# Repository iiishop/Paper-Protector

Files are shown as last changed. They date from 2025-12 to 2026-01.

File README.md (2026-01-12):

# Paper Protector

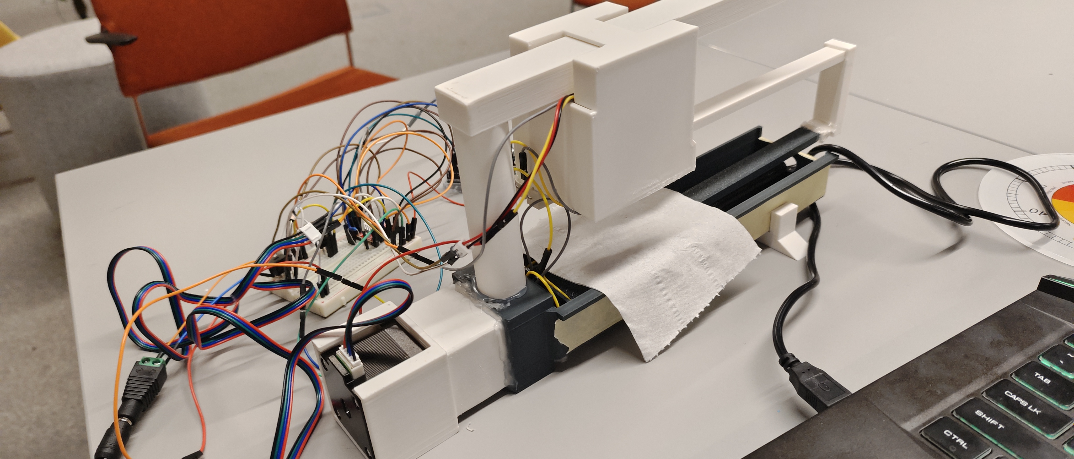
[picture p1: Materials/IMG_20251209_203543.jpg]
Paper Protector Prototype


---

## Video Demonstration

**Watch the system in action**: [Paper Protector Demo on Bilibili](https://www.bilibili.com/video/BV1xwraBiE8S)

*The video file is also available in this repository at [`Materials/QQ视频20260112051459 (online-video-cutter.com).mp4`](https://github.com/iiishop/Paper-Protector/blob/main/Materials/QQ%E8%A7%86%E9%A2%9120260112051459%20(online-video-cutter.com).mp4), but GitHub may not display it directly due to file size. Please use the Bilibili link above for online viewing.*

---

## 1. What it does

This project is an automated paper preservation system that detects and removes localized moisture from documents through precision scanning and targeted thermal intervention.

**Scanning Mode**: The device performs incremental X-axis scanning with a NEMA 17 stepper motor, moving at 1.498mm per revolution. During the scan:
- **DHT22 sensor** (Phase 2): Monitors real-time humidity and temperature with EMA filtering (α=0.3) to compensate for sensor lag.
- **AS7341-V2 NIR sensor** (Phase 1, damaged): Previously detected moisture at 60Hz via water molecule absorption spectra using 850nm IR LEDs.
- **Forced-induction sampling**: A 5015 fan at 50% power actively pushes moisture through paper fibres toward the sensor, accelerating response time from ~5s to ~2s.
- **Position tracking**: Non-blocking motor control ensures each reading corresponds to a precise spatial coordinate, generating ~140 data points over a 210mm path.

**Wet Spot Detection**: The web interface analyzes scan data using gradient-based dynamic threshold adjustment:
- **Humidity gradient calculation**: Detects rising/falling trends to predict true moisture levels.
- **Hysteresis compensation**: Lowers threshold by 30% during rising trends; raises by 10% during falling trends to avoid false positives.
- **Spatial mapping**: Blue circular markers with percentage overlays appear on the digital twin interface, indicating exact locations of moisture (>threshold RH%).

**Drying Mode**: Once wet spots are identified, the system applies localized thermal intervention:
- **10W heating array** (two 10Ω 10W resistors): PWM-controlled (0-255 range) for adjustable heat intensity.
- **5015 centrifugal fan**: PWM-controlled airflow (0-255 range) for forced-convection drying.
- **Efficiency**: Achieves ~8× faster moisture removal compared to natural evaporation (45s vs 358s for 15% RH reduction).
- **S-curve drying profile**: Initial lag (0-5s) due to sensor equilibration, rapid phase (5-27s), deceleration near equilibrium (27-45s).

**Web Dashboard**: Real-time "Digital Twin" interface with <200ms telemetry latency:
- **Visualization Zone**: Animated paper strip with synchronized red position indicator, horizontal humidity bar chart, and persistent wet spot markers.
- **Control Zone**: Live actuator telemetry (0-255 PWM values), adjustable scan length (up to 210mm), moisture threshold calibration (Zero-set), and manual motor/fan/heater control.
- **Serial PubSub Protocol**: Topic-based MQTT-like messaging (`topic:payload\n`) over USB serial for bidirectional Arduino-Python-WebSocket communication.

**Calibration**: Mandatory "Zero-set" routine establishes baseline humidity for different paper stocks, neutralizing material hygroscopicity before scanning.

---

## 2. Hardware

### Bill of Materials (BOM)

| **Category** | **Component** | **Specifications** | **Qty** | **Notes** |
|---|---|---|---|---|
| **Microcontroller** | Arduino Uno (Rev3) - ICSP | ATmega328P, 16MHz | 1 | Central controller with USB serial interface |
| **Motion Control** | NEMA 17 Stepper Motor | Bipolar, 1.8° step angle, 2.4 kg·cm holding torque, 15.4V, 0.28A | 1 | Lead screw drive for X-axis scanning (1.498mm/rev) |
|  | Pololu A4988 Driver | SO16 package, micro-stepping capable | 1 | Stepper motor driver with current limiting |
| **Environmental Sensing** | DHT22 Sensor | Digital output, 3.3-5.5V DC, polymer humidity capacitor | 1 | **Phase 2**: Current humidity/temperature sensor |
|  | AS7341-V2 NIR Sensor (optional) | 10-channel spectral sensor, 850nm IR LEDs ×4 | 1 | **Phase 1**: High-speed moisture detection (damaged) |
| **Thermal Intervention** | 5015 Centrifugal Fan | 12V DC, 50×50×15mm | 1 | Forced-convection airflow for drying and sampling |
|  | 10Ω 10W Resistors | SMD 2512 package, ±5% tolerance | 2 | Series-connected heating array (20Ω total, 10W) |
| **Power Electronics** | N-Channel MOSFETs | TO-220 package, PTH | 2 | PWM control for fan and heater (separate channels) |
|  | 12V DC Power Supply | With power plug | 1 | External supply for high-current actuators |
|  | Rectifier Diode | 1N4001, MELF DO-213 AB (SMD) | 1 | Reverse polarity protection |
|  | Electrolytic Capacitor | 0.1mF (100µF), 25V, 100 mil THT | 1 | Power supply filtering |
| **Passive Components** | 10kΩ Resistor | 0.25W, ±5%, 4-band, THT, 400 mil pitch | 1 | Pull-down/pull-up resistor for MOSFET gates |
| **Assembly** | Breadboard (or Perfboard) | Standard 830-point breadboard | 1 | **Option A**: Breadboard for prototyping<br>**Option B**: Solder onto perfboard for permanent installation |
|  | Jumper Wires | DuPont connectors, assorted lengths | Various | Male-to-male, male-to-female for breadboard connections |
| **Mechanical** | 3D-Printed Enclosure | PLA material | 1 | Custom housing for motor and lead screw assembly |
|  | Lead Screw & Nut | T8 lead screw, 8mm diameter | 1 | Linear motion conversion (1.498mm per motor revolution) |
|  | Stainless Steel Mesh | Fine mesh for paper support | 1 | Allows airflow through paper during forced-induction sampling |

### Assembly Notes:
- **Split-Power Architecture**: Arduino Uno powered via USB (5V logic); 12V rail for motor, fan, and heater via external supply.
- **Voltage Isolation**: Keep 12V actuator power rail electrically isolated from 3.3V/5V logic to prevent sensor damage.
- **MOSFET Configuration**: Use 10kΩ pull-down resistors on MOSFET gates; Arduino PWM pins (D5, D6) control fan and heater independently.
- **Breadboard vs. Soldering**: Breadboard recommended for initial testing; migrate to perfboard for reduced noise and improved reliability in production use.

---

## 3. Wiring Diagram

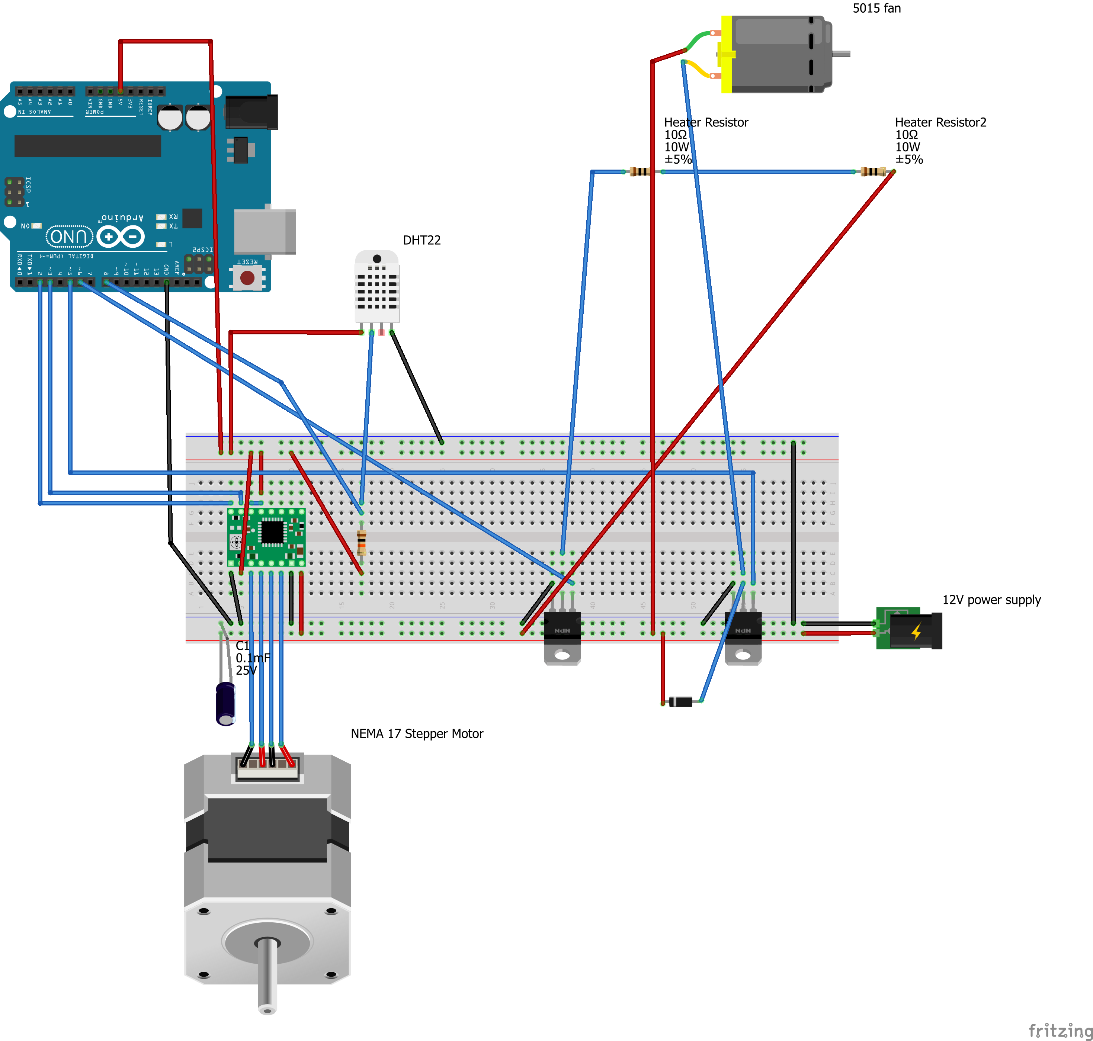
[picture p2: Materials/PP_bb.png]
Breadboard wiring diagram

**Figure 1: Complete breadboard wiring layout** - Shows connections between Arduino Uno, A4988 stepper driver, DHT22 sensor, N-channel MOSFETs, and power distribution. The diagram illustrates the split-power architecture with USB power for logic (5V) and external 12V DC supply for actuators (motor, fan, heater).

---

## 4. Libraries

### Arduino Libraries (Install via Arduino IDE Library Manager)

| **Library** | **Author** | **Version** | **Use Case** | **Installation** |
|---|---|---|---|---|
| **DHT sensor library** | Adafruit | ≥1.4.4 | **Phase 2**: DHT22 temperature/humidity sensor | `Sketch → Include Library → Manage Libraries → Search "DHT sensor library"` |
| **Adafruit AS7341** | Adafruit | ≥1.3.0 | **Phase 1**: AS7341-V2 NIR sensor (optional) | `Sketch → Include Library → Manage Libraries → Search "Adafruit AS7341"` |

**Dependency**: Both libraries require **Adafruit Unified Sensor** library (automatically installed).

### Sensor Selection:
- **Current Implementation (Phase 2)**: Install **DHT sensor library** for DHT22 sensor with forced-induction compensation.
- **Optional (Phase 1)**: Install **Adafruit AS7341** for high-speed NIR moisture detection at 60Hz (requires AS7341-V2 sensor and 850nm IR LEDs).

**Note**: The codebase supports both sensors; uncomment the appropriate `#include` directive in `PaperProtector.ino` based on your hardware configuration.

---

## 5. How to Run

### Step 1: Clone the Repository
```bash
git clone https://github.com/iiishop/Paper-Protector
cd Paper-Protector
```

### Step 2: Open Arduino Project
Open `Backend/PaperProtector/PaperProtector.ino` in Arduino IDE.

### Step 3: Install Required Libraries
Install the necessary Arduino libraries via **Library Manager** (see [Section 4: Libraries](#4-libraries)):
- **DHT sensor library** by Adafruit (for DHT22 sensor)
- OR **Adafruit AS7341** by Adafruit (for AS7341-V2 NIR sensor, optional)

### Step 4: Hardware Connection
1. Assemble the circuit according to the [Wiring Diagram](#3-wiring-diagram).
2. Connect Arduino Uno to your computer via USB Type-B cable.
3. Connect the 12V external power supply to the breadboard power rail.

### Step 5: Upload Firmware to Arduino
1. Select **Board**: `Tools → Board → Arduino Uno`
2. Select **Port**: `Tools → Port → COM# (Arduino Uno)` (on Windows) or `/dev/ttyUSB#` (on Linux/Mac)
3. Click **Upload** (→ button) to flash the firmware.
4. **CRITICAL**: After successful upload, **close the Arduino IDE Serial Monitor** to free the COM port for Python backend communication.

### Step 6: Start Python Backend Server
Navigate to the Python backend directory and run the server:

```bash
cd Backend/Python
python main.py
```

**Expected Output**:
```
[INFO] Serial port connected: COM3
[INFO] WebSocket server started on ws://localhost:8765
```

**Troubleshooting**:
- If Python dependencies are missing, install via: `pip install -r requirements.txt`
- If COM port is blocked, ensure Arduino IDE Serial Monitor is closed.

### Step 7: Open Web Dashboard
Open `Frontend/index.html` in a modern web browser (Chrome/Edge recommended):

```bash
# Option A: Direct file open
# Navigate to: file:///path/to/Paper-Protector/Frontend/index.html

# Option B: Local HTTP server (recommended for WebSocket compatibility)
cd Frontend
python -m http.server 8080
# Then open: http://localhost:8080/index.html
```

The dashboard should display:
- Real-time humidity/temperature readings
- Motor position indicator (red line)
- Live actuator telemetry (fan/heater PWM values)
- Calibration and scanning controls

**System is now ready for operation!** Proceed to calibration (Zero-set) before first scan.

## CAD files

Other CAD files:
Paper Protector v13.f3d

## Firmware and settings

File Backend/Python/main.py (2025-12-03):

"""
Bridge Server - FastAPI application entry point
Connects Arduino serial communication with WebSocket clients
"""
import asyncio
import logging
import json
from contextlib import asynccontextmanager
from fastapi import FastAPI, WebSocket, WebSocketDisconnect, HTTPException
from fastapi.middleware.cors import CORSMiddleware
from pydantic import BaseModel
import argparse

from config import config
from websocket_manager import WebSocketManager
from serial_handler import SerialHandler

# Configure logging
logging.basicConfig(
    level=logging.INFO,
    format='%(asctime)s - %(name)s - %(levelname)s - %(message)s'
)
logger = logging.getLogger(__name__)

# Global instances
ws_manager = WebSocketManager(max_connections=config.max_ws_connections)
serial_handler = SerialHandler(
    port=config.serial_port,
    baudrate=config.baudrate,
    timeout=config.serial_timeout,
    reconnect_interval=config.reconnect_interval
)


async def serial_to_websocket_task():
    """
    Background task: continuously read from serial and broadcast to WebSocket clients
    """
    logger.info("Starting serial-to-websocket routing task")
    
    while True:
        try:
            if serial_handler.is_connected:
                # Read message from serial port
                message = await serial_handler.read_message()
                
                if message:
                    logger.debug(f"Routing message from Arduino: {message['topic']}")
                    
                    # Broadcast to all WebSocket clients
                    await ws_manager.broadcast({
                        'type': 'message',
                        'topic': message['topic'],
                        'payload': message['payload'],
                        'source': 'arduino'
                    })
                else:
                    # No message available, small delay
                    await asyncio.sleep(0.01)
            else:
                # Wait a bit if not connected
                await asyncio.sleep(0.5)
        
        except asyncio.CancelledError:
            logger.info("Serial-to-websocket task cancelled")
            break
        except Exception as e:
            logger.error(f"Error in serial-to-websocket task: {e}", exc_info=True)
            
            # Handle disconnection
            if serial_handler.is_connected:
                await serial_handler.handle_disconnect()
            
            await asyncio.sleep(1)


async def serial_status_callback(connected: bool):
    """
    Callback for serial connection status changes
    Notifies all WebSocket clients of status changes
    """
    status = 'connected' if connected else 'disconnected'
    logger.info(f"Serial status changed: {status}")
    
    await ws_manager.broadcast_status(status, {
        'serial_port': config.serial_port,
        'baudrate': config.baudrate
    })


@asynccontextmanager
async def lifespan(app: FastAPI):
    """
    Lifespan context manager for startup and shutdown events
    Replaces the deprecated @app.on_event decorators
    """
    # Startup
    logger.info("Bridge Server starting...")
    logger.info(f"Serial port: {config.serial_port}")
    logger.info(f"Baudrate: {config.baudrate}")
    logger.info(f"WebSocket: {config.ws_host}:{config.ws_port}")
    
    # Register status callback
    serial_handler.add_status_callback(serial_status_callback)
    
    # Start serial reconnection loop
    await serial_handler.start_reconnect_loop()
    
    # Start serial-to-websocket routing task
    asyncio.create_task(serial_to_websocket_task())
    
    logger.info("Bridge Server started successfully")
    
    yield  # Server is running
    
    # Shutdown
    logger.info("Bridge Server shutting down...")
    
    # Stop reconnection loop
    await serial_handler.stop_reconnect_loop()
    
    # Disconnect serial
    await serial_handler.disconnect()
    
    logger.info("Bridge Server shutdown complete")


# Create FastAPI application with lifespan
app = FastAPI(
    title="Arduino Bridge Server",
    description="Bridge between Arduino serial communication and WebSocket clients",
    version="1.0.0",
    lifespan=lifespan
)

# Configure CORS
app.add_middleware(
    CORSMiddleware,
    allow_origins=["*"],  # In production, specify exact origins
    allow_credentials=True,
    allow_methods=["*"],
    allow_headers=["*"],
)


class PublishRequest(BaseModel):
    """Request model for publishing messages"""
    topic: str
    payload: str


@app.get("/")
async def root():
    """Root endpoint"""
    return {
        "message": "Arduino Bridge Server",
        "version": "1.0.0",
        "status": "running"
    }


@app.get("/api/status")
async def get_status():
    """
    Get the current status of the bridge server
    
    Returns:
        Status information including serial connection state
    """
    return {
        "serial": {
            "connected": serial_handler.is_connected,
            "port": config.serial_port,
            "baudrate": config.baudrate
        },
        "websocket": {
            "active_connections": ws_manager.get_connection_count(),
            "max_connections": config.max_ws_connections
        },
        "server": {
            "status": "running",
            "version": "1.0.0"
        }
    }


@app.post("/api/publish")
async def publish_message(request: PublishRequest):
    """
    Publish a message to Arduino via serial port
    
    Args:
        request: PublishRequest with topic and payload
        
    Returns:
        Success status and message details
        
    Raises:
        HTTPException: If serial port is not connected or write fails
    """
    if not serial_handler.is_connected:
        raise HTTPException(
            status_code=503,
            detail="Serial port not connected"
        )
    
    # Validate input
    if not request.topic:
        raise HTTPException(
            status_code=400,
            detail="Topic cannot be empty"
        )
    
    # Send message to serial port
    success = await serial_handler.write_message(request.topic, request.payload)
    
    if not success:
        raise HTTPException(
            status_code=500,
            detail="Failed to write to serial port"
        )
    
    return {
        "success": True,
        "topic": request.topic,
        "payload": request.payload,
        "message": "Message published successfully"
    }


@app.websocket("/ws")
async def websocket_endpoint(websocket: WebSocket):
    """
    WebSocket endpoint for client connections
    Handles bidirectional communication between web clients and Arduino
    """
    client_id = id(websocket)
    logger.info(f"New WebSocket connection attempt from client {client_id}")
    
    # Accept the connection
    if not await ws_manager.connect(websocket):
        logger.warning(f"Connection rejected for client {client_id}: limit reached")
        await websocket.close(code=1008, reason="Connection limit reached")
        return
    
    try:
        # Send initial connection status
        await ws_manager.send_personal({
            'type': 'status',
            'status': 'connected' if serial_handler.is_connected else 'disconnected',
            'details': {
                'serial_port': config.serial_port,
                'baudrate': config.baudrate
            }
        }, websocket)
        
        logger.info(f"Client {client_id} connected successfully")
        
        # Handle incoming messages from this client
        while True:
            # Receive message from WebSocket client
            data = await websocket.receive_text()
            
            try:
                message = json.loads(data)
                message_type = message.get('type', 'publish')
                
                if message_type == 'publish':
                    # Forward publish message to Arduino via serial
                    topic = message.get('topic', '')
                    payload = message.get('payload', '')
                    
                    if topic:
                        logger.debug(f"Client {client_id} publishing: {topic}:{payload}")
                        success = await serial_handler.write_message(topic, payload)
                        
                        if not success:
                            logger.warning(f"Failed to write message from client {client_id}")
                        
                        # Send acknowledgment back to sender
                        await ws_manager.send_personal({
                            'type': 'ack',
                            'success': success,
                            'topic': topic
                        }, websocket)
                    else:
                        logger.warning(f"Client {client_id} sent message without topic")
                        await ws_manager.send_personal({
                            'type': 'error',
                            'message': 'Topic is required'
                        }, websocket)
                
                elif message_type == 'ping':
                    # Respond to ping with pong
                    await ws_manager.send_personal({
                        'type': 'pong'
                    }, websocket)
                
                else:
                    logger.warning(f"Unknown message type from client {client_id}: {message_type}")
                
            except json.JSONDecodeError as e:
                logger.error(f"Invalid JSON from client {client_id}: {data[:100]}")
                await ws_manager.send_personal({
                    'type': 'error',
                    'message': 'Invalid JSON format'
                }, websocket)
            except Exception as e:
                logger.error(f"Error processing message from client {client_id}: {e}", exc_info=True)
                await ws_manager.send_personal({
                    'type': 'error',
                    'message': 'Internal server error'
                }, websocket)
    
    except WebSocketDisconnect:
        logger.info(f"Client {client_id} disconnected normally")
    except Exception as e:
        logger.error(f"WebSocket error for client {client_id}: {e}", exc_info=True)
    finally:
        await ws_manager.disconnect(websocket)
        logger.info(f"Client {client_id} cleanup complete")


def main():
    """Main entry point with argument parsing"""
    parser = argparse.ArgumentParser(description="Arduino Bridge Server")
    parser.add_argument("--port", type=str, help="Serial port (e.g., COM3 or /dev/ttyUSB0)")
    parser.add_argument("--baudrate", type=int, help="Serial baudrate (default: 9600)")
    parser.add_argument("--host", type=str, default="0.0.0.0", help="WebSocket host")
    parser.add_argument("--ws-port", type=int, default=8000, help="WebSocket port")
    
    args = parser.parse_args()
    
    # Update configuration from arguments
    config.update_from_args(port=args.port, baudrate=args.baudrate)
    if args.host:
        config.ws_host = args.host
    if args.ws_port:
        config.ws_port = args.ws_port
    
    # Run the server
    import uvicorn
    uvicorn.run(app, host=config.ws_host, port=config.ws_port)


if __name__ == "__main__":
    main()

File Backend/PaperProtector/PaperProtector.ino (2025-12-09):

#include "SerialPubSub.h"
#include "StepperMotor.h"
#include "FanController.h"
#include "DHT22Sensor.h"
#include "Heater.h"
// #include "MoistureSensor.h"  // 暂时不使用 AS7341 和 IR LED

#define DIR_PIN 2
#define STEP_PIN 3
#define FAN_PIN 5
#define DHT_PIN 8
#define HEATER_PIN 6
// #define IRLED_PIN 4  // 暂时不使用

SerialPubSub pubsub;

StepperMotor stepper(&pubsub, DIR_PIN, STEP_PIN);

FanController fan(&pubsub, FAN_PIN);

DHT22Sensor dhtSensor(&pubsub, DHT_PIN);

Heater heater(&pubsub, HEATER_PIN);

// MoistureSensor moistureSensor(&pubsub, IRLED_PIN);  // 暂时不使用

void setup()
{
    pubsub.begin(9600);

    delay(1000);

    while (Serial.available())
    {
        Serial.read();
    }

    pubsub.publish("system/status", "ready");

    stepper.begin();

    fan.begin();

    dhtSensor.begin();

    heater.begin();

    // 暂时不使用 AS7341 传感器和 IR LED
    // // 清空缓冲区
    // while (Serial.available())
    // {
    //     Serial.read();
    // }

    // // 最后初始化可能阻塞的传感器
    // moistureSensor.begin();

    // // 再次清空缓冲区
    // while (Serial.available())
    // {
    //     Serial.read();
    // }

    // 发布初始状态
    pubsub.publish("system/status", "initialized");
}

void loop()
{
    pubsub.loop();

    stepper.loop();

    fan.loop();

    dhtSensor.loop();

    heater.loop();

    // moistureSensor.loop();  // 暂时不使用
}

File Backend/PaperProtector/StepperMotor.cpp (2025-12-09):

#include "StepperMotor.h"

// 静态实例指针初始化
StepperMotor *StepperMotor::_instance = nullptr;

// 构造函数
StepperMotor::StepperMotor(SerialPubSub *pubsub, int dirPin, int stepPin)
    : _pubsub(pubsub),
      _dirPin(dirPin),
      _stepPin(stepPin),
      _stepsPerRevolution(200), // 默认200步/圈 (1.8度步进角)
      _stepDelayMicros(1000),   // 默认1000微秒延迟
      _isBusy(false),
      _currentSteps(0),       // 初始位置为0
      _mmPerRevolution(1.498) // 实测每圈1.498mm (134.8mm / 90圈)
{
    _instance = this;
}

// 初始化方法 - 配置引脚和订阅主题
void StepperMotor::begin()
{
    // 配置DIR和STEP引脚为输出模式
    pinMode(_dirPin, OUTPUT);
    pinMode(_stepPin, OUTPUT);

    // 设置初始状态
    digitalWrite(_dirPin, LOW);
    digitalWrite(_stepPin, LOW);

    // 订阅motor/rotate主题
    _pubsub->subscribe("motor/rotate", messageCallback);

    // 订阅motor/config主题
    _pubsub->subscribe("motor/config", configCallback);

    // 订阅motor/calibrate主题（校准/调零）
    _pubsub->subscribe("motor/calibrate", calibrateCallback);

    // 订阅motor/home主题（回零）
    _pubsub->subscribe("motor/home", homeCallback);

    // 订阅motor/position/get主题（查询位置）
    _pubsub->subscribe("motor/position/get", positionCallback);

    // 订阅motor/moveto主题（移动到指定mm位置）
    _pubsub->subscribe("motor/moveto", moveToCallback);

    // 发布初始配置和位置
    publishConfig();
    publishPosition();
}

// 循环处理方法（当前为空，预留用于非阻塞实现）
void StepperMotor::loop()
{
    // 预留用于未来的非阻塞实现
}

// 旋转指定圈数
void StepperMotor::rotate(float revolutions)
{
    executeRotation(revolutions);
}

// 移动到指定毫米位置
void StepperMotor::moveTo(float targetMm)
{
    // 计算当前位置（mm）
    long currentRevolutions_x100 = (_currentSteps * 100L) / _stepsPerRevolution;
    float currentMm = (float)currentRevolutions_x100 / 100.0 * _mmPerRevolution;

    // 计算需要移动的距离
    float deltaMm = targetMm - currentMm;

    // 转换为圈数
    float revolutions = deltaMm / _mmPerRevolution;

    // 执行移动
    executeRotation(revolutions);
}

// 设置每圈步数
void StepperMotor::setStepsPerRevolution(int steps)
{
    _stepsPerRevolution = steps;
}

// 设置步进延迟
void StepperMotor::setStepDelay(unsigned long delayMicros)
{
    _stepDelayMicros = delayMicros;
}

// 获取忙碌状态
bool StepperMotor::isBusy() const
{
    return _isBusy;
}

// 静态消息回调函数
void StepperMotor::messageCallback(const char *topic, const char *payload)
{
    if (_instance != nullptr)
    {
        // 检查payload是否为空
        if (payload == nullptr || payload[0] == '\0')
        {
            _instance->publishError("Invalid number format");
            return;
        }

        // 验证payload是否为有效数字格式
        bool isValid = false;
        bool hasDigit = false;
        bool hasDecimal = false;
        int i = 0;

        // 允许开头的正负号
        if (payload[i] == '-' || payload[i] == '+')
        {
            i++;
        }

        // 检查剩余字符
        while (payload[i] != '\0')
        {
            if (payload[i] >= '0' && payload[i] <= '9')
            {
                hasDigit = true;
            }
            else if (payload[i] == '.' && !hasDecimal)
            {
                hasDecimal = true;
            }
            else
            {
                // 遇到无效字符
                _instance->publishError("Invalid number format");
                return;
            }
            i++;
        }

        // 必须至少有一个数字
        if (!hasDigit)
        {
            _instance->publishError("Invalid number format");
            return;
        }

        // 解析payload为浮点数
        float revolutions = atof(payload);

        // 检查电机是否忙碌
        if (_instance->isBusy())
        {
            _instance->publishError("Motor busy");
            return;
        }

        // 执行旋转
        _instance->rotate(revolutions);
    }
}

// 执行旋转操作
void StepperMotor::executeRotation(float revolutions)
{
    // 设置忙碌状态
    _isBusy = true;

    // 发布rotating状态
    publishStatus("rotating");

    // 设置方向引脚
    if (revolutions >= 0)
    {
        digitalWrite(_dirPin, HIGH); // 正数 = 顺时针
    }
    else
    {
        digitalWrite(_dirPin, LOW); // 负数 = 逆时针
    }

    // 计算总步数
    long totalSteps = (long)(abs(revolutions) * _stepsPerRevolution);

    // 生成步进脉冲
    for (long i = 0; i < totalSteps; i++)
    {
        digitalWrite(_stepPin, HIGH);
        delayMicroseconds(_stepDelayMicros);
        digitalWrite(_stepPin, LOW);
        delayMicroseconds(_stepDelayMicros);
    }

    // 更新当前步数
    if (revolutions >= 0)
    {
        _currentSteps += totalSteps;
    }
    else
    {
        _currentSteps -= totalSteps;
    }

    // 清除忙碌状态
    _isBusy = false;

    // 发布完成状态和位置
    publishStatus("idle");
    publishPosition();
}

// 发布状态消息
void StepperMotor::publishStatus(const char *status)
{
    _pubsub->publish("motor/status", status);
}

// 发布错误消息
void StepperMotor::publishError(const char *error)
{
    _pubsub->publish("motor/error", error);
}
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

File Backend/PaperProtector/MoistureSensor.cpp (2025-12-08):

#include "MoistureSensor.h"

// 静态成员初始化
MoistureSensor *MoistureSensor::_instance = nullptr;

MoistureSensor::MoistureSensor(SerialPubSub *pubsub, int irledPin)
    : _pubsub(pubsub),
      _irledPin(irledPin),
      _irledState(false),
      _lastMeasurementTime(0),
      _gain(AS7341_GAIN_128X),
      _integrationTime(100)
{

    // 初始化校准数据
    _calibration.dryBaseline = 0.0;
    _calibration.wetBaseline = 0.0;
    _calibration.timestamp = 0;
    _calibration.isValid = false;

    // 设置静态实例指针
    _instance = this;
}

bool MoistureSensor::begin()
{
    // 配置IRLED引脚为输出模式
    pinMode(_irledPin, OUTPUT);
    setIRLED(false); // 初始状态关闭

    // 订阅 IR LED 控制主题(独立于传感器,总是可用)
    _pubsub->subscribe("irled/control", irledControlCallback);
    _pubsub->subscribe("irled/get", irledGetCallback);

    // 发布初始 LED 状态
    _pubsub->publish("irled/status", "off");

    // 初始化AS7341传感器
    if (!_sensor.begin())
    {
        publishError("AS7341 sensor not found");
        _pubsub->publish("moisture/status", "sensor_error");
        // 即使传感器失败,IR LED 控制仍然可用
        return false;
    }

    // 配置传感器参数
    _sensor.setGain(_gain);
    _sensor.setATIME(_integrationTime);

    // 订阅湿度传感器相关主题
    _pubsub->subscribe("moisture/measure", measureCallback);
    _pubsub->subscribe("moisture/calibrate", calibrateCallback);
    _pubsub->subscribe("moisture/config", configCallback);

    // 发布初始化成功消息
    _pubsub->publish("moisture/status", "ready");

    return true;
}

void MoistureSensor::loop()
{
    // 处理SerialPubSub消息
    // SerialPubSub的loop()方法在主程序中调用，这里不需要重复调用
    // 此方法保留用于未来的异步处理逻辑

    // 当前实现：所有消息处理通过回调函数完成
    // 测量频率限制在measure()方法中实现
    // 传感器饱和处理在measure()方法中实现
}

MoistureSensor::MeasurementResult MoistureSensor::measure()
{
    MeasurementResult result = {false, 0.0, false};

    // 检查测量频率限制（最小间隔500ms）
    unsigned long currentTime = millis();
    if (currentTime - _lastMeasurementTime < MIN_MEASUREMENT_INTERVAL)
    {
        publishError("Measurement too frequent");
        return result;
    }
    _lastMeasurementTime = currentTime;

    // 重试机制（最多3次）
    for (int retry = 0; retry < MAX_RETRIES; retry++)
    {
        uint16_t readings[12];

        // 步骤1: 测量环境光强度（IRLED关闭）
        setIRLED(false);

        if (!_sensor.readAllChannels(readings))
        {
            // 读取失败，重试
            if (retry < MAX_RETRIES - 1)
            {
                delay(RETRY_DELAY_MS);
            }
            continue;
        }

        // 检查环境光是否饱和
        if (handleSaturation(readings))
        {
            // 增益已调整，重新测量
            if (retry < MAX_RETRIES - 1)
            {
                delay(RETRY_DELAY_MS);
            }
            continue;
        }

        float ambientIntensity = readings[AS7341_CHANNEL_NIR];

        // 步骤2: 打开IRLED并测量总光强度
        setIRLED(true);

        if (!_sensor.readAllChannels(readings))
        {
            setIRLED(false); // 确保关闭LED
            // 读取失败，重试
            if (retry < MAX_RETRIES - 1)
            {
                delay(RETRY_DELAY_MS);
            }
            continue;
        }

        // 检查反射光是否饱和
        if (handleSaturation(readings))
        {
            setIRLED(false); // 确保关闭LED
            // 增益已调整，重新测量
            if (retry < MAX_RETRIES - 1)
            {
                delay(RETRY_DELAY_MS);
            }
            continue;
        }

        float totalIntensity = readings[AS7341_CHANNEL_NIR];

        // 步骤3: 测量完成后关闭IRLED
        setIRLED(false);

        // 步骤4: 计算净反射光强度
        float reflectedIntensity = totalIntensity - ambientIntensity;
        if (reflectedIntensity < 0)
        {
            reflectedIntensity = 0;
        }

        // 测量成功，检测纸张存在性
        result.paperPresent = detectPaper(reflectedIntensity, ambientIntensity);
        result.isValid = true;

        // 如果有纸张，调用calculateMoisture()计算湿度
        if (result.paperPresent)
        {
            result.moisturePercent = calculateMoisture(reflectedIntensity);
        }
        else
        {
            result.moisturePercent = 0.0;
        }

        // 返回MeasurementResult结构体
        return result;
    }

    // 所有重试失败
    publishError("Sensor communication failed after retries");
    return result;
}

float MoistureSensor::readAmbientIntensity()
{
    uint16_t readings[12];

    // 确保IRLED关闭
    setIRLED(false);

    if (!_sensor.readAllChannels(readings))
    {
        return -1.0; // 读取失败
    }

    // 返回NIR通道的环境光强度
    return readings[AS7341_CHANNEL_NIR];
}

float MoistureSensor::readNIRIntensity()
{
    uint16_t readings[12];

    // 步骤1: 测量环境光强度（IRLED关闭）
    setIRLED(false);

    if (!_sensor.readAllChannels(readings))
    {
        return -1.0; // 读取失败
    }

    // 获取NIR通道的环境光强度
    float ambientIntensity = readings[AS7341_CHANNEL_NIR];

    // 步骤2: 打开IRLED并测量总光强度
    setIRLED(true);

    if (!_sensor.readAllChannels(readings))
    {
        setIRLED(false); // 确保关闭LED
        return -1.0;     // 读取失败
    }

    // 获取NIR通道的总光强度
    float totalIntensity = readings[AS7341_CHANNEL_NIR];

    // 步骤3: 测量完成后关闭IRLED
    setIRLED(false);

    // 步骤4: 计算净反射光强度（总光强度 - 环境光）
    float reflectedIntensity = totalIntensity - ambientIntensity;

    // 确保返回值非负
    if (reflectedIntensity < 0)
    {
        reflectedIntensity = 0;
    }

    return reflectedIntensity;
}

bool MoistureSensor::detectPaper(float intensity, float ambient)
{
    // 纸张检测阈值：反射光强度 > 环境光 * 1.5
    // 这确保反射光明显高于环境光，表示有纸张存在
    const float PAPER_DETECTION_THRESHOLD = 1.5;

    return intensity > (ambient * PAPER_DETECTION_THRESHOLD);
}

float MoistureSensor::calculateMoisture(float intensity)
{
    float moisture = 0.0;

    // 检查校准数据是否有效
    if (_calibration.isValid && _calibration.dryBaseline > _calibration.wetBaseline)
    {
        // 使用校准的线性插值模型
        // moisture% = 100 * (I_dry - I_reflected) / (I_dry - I_wet)
        float numerator = _calibration.dryBaseline - intensity;
        float denominator = _calibration.dryBaseline - _calibration.wetBaseline;

        // 避免除以零
        if (denominator > 0.1)
        {
            moisture = 100.0 * numerator / denominator;
        }
        else
        {
            // 校准数据无效（干湿基准太接近）
            moisture = 0.0;
        }
    }
    else
    {
        // 未校准情况：使用默认映射
        // 假设典型的NIR反射范围：干燥纸张 ~1000-2000，湿润纸张 ~200-500
        // 使用简单的线性映射作为默认值
        const float DEFAULT_DRY_BASELINE = 1500.0;
        const float DEFAULT_WET_BASELINE = 300.0;

        float numerator = DEFAULT_DRY_BASELINE - intensity;
        float denominator = DEFAULT_DRY_BASELINE - DEFAULT_WET_BASELINE;

        moisture = 100.0 * numerator / denominator;
    }

    // 确保返回值在[0, 100]范围内
    if (moisture < 0.0)
    {
        moisture = 0.0;
    }
    else if (moisture > 100.0)
    {
        moisture = 100.0;
    }

    return moisture;
}
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

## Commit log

2025-12-02 feat(backend): Add SerialPubSub publish-subscribe library for Arduino
    - Add SerialPubSub.h header file with class definition and message callback interface
    - Add SerialPubSub.cpp implementation with full pub/sub functionality
    - Add PaperPropector.ino main sketch file with SerialPubSub initialization
    - Implement publish() method with overloads for string, int, float, and bool types
    - Implement subscribe() method to register topic callbacks with validation
    - Implement unsubscribe() method to remove topic subscriptions
    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
2025-12-02 feat(backend): Add Python Bridge Server for Arduino serial-WebSocket communication
    - Create FastAPI application to bridge Arduino serial communication with WebSocket clients
    - Add configuration management module with environment variable support for serial and WebSocket settings
    - Implement SerialHandler class for managing Arduino serial port connections with automatic reconnection
    - Implement WebSocketManager class for managing multiple concurrent WebSocket client connections
    - Add message routing between serial port and WebSocket clients with pub/sub pattern support
    - Create REST API endpoints for status monitoring and publishing messages to Arduino
    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
2025-12-02 feat(frontend): Add dashboard UI with module loader and PubSub client
    - Add main application initialization with PubSubClient and ModuleLoader
    - Add dynamic module loading system with lifecycle management
    - Add WebSocket PubSub client for real-time communication
    - Add Serial Monitor module for Arduino serial data visualization
    - Add responsive dashboard layout with connection status indicator
    - Add modular CSS styling for dashboard and module components
    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
2025-12-03 refactor(backend): Replace deprecated event decorators with lifespan context manager
    - Update serial port default from COM3 to COM6 in config.py
    - Replace @app.on_event("startup") and @app.on_event("shutdown") decorators with asynccontextmanager lifespan pattern
    - Move FastAPI app initialization and CORS middleware configuration after lifespan definition
    - Add contextlib asynccontextmanager import for modern FastAPI lifecycle management
    - Consolidate startup and shutdown logic into single lifespan context manager with yield separator
    - Improves code maintainability by using FastAPI's recommended lifespan pattern instead of deprecated event decorators
    [config.py, main.py]
2025-12-04 chore(backend): Fix typo in PaperProtector directory name
    - Rename directory from "PaperPropector" to "PaperProtector"
    - Move PaperProtector.ino to corrected directory path
    - Move SerialPubSub.cpp to corrected directory path
    - Move SerialPubSub.h to corrected directory path
    - Corrects misspelling in project directory structure for consistency
    [PaperProtector.ino, SerialPubSub.cpp]
2025-12-04 feat(backend): Add StepperMotor control module with PubSub integration
    - Add StepperMotor.h header with class definition and pin configuration
    - Add StepperMotor.cpp implementation with motor control logic
    - Implement PubSub message callbacks for motor/rotate and motor/config topics
    - Add motor rotation with configurable steps per revolution and step delay
    - Add status publishing (rotating, idle) and error handling
    - Update PaperProtector.ino to initialize and integrate StepperMotor module
    - Add stepper_debug.html frontend module for motor testing and debugging
    - Update module_loader.js to support dynamic module loading
    - Update app.js to initialize stepper debug module on startup
    - Enable A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
    [PaperProtector.ino, StepperMotor.cpp]
2025-12-04 feat(frontend,backend): Add FanController module with Arduino and UI integration
    - Add FanController.cpp and FanController.h for Arduino fan speed control via PWM
    - Implement fan speed callback with input validation and error handling
    - Add fan/speed, fan/query, and fan/status PubSub topics for fan communication
    - Integrate FanController into PaperProtector.ino main sketch
    - Add fan_control.html module UI for frontend fan control interface
    - Add fan_control.css styling for fan control module
    - Register fan_control module in app.js with auto-load on connection
    - Update module_loader.js to append modules instead of replacing container
    - Add Serial status change handler in pubsub_client.js for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
    [PaperProtector.ino]
2025-12-08 feat(frontend,backend): Add MoistureSensor module with Arduino and UI integration
    - Add MoistureSensor.cpp and MoistureSensor.h for Arduino-based moisture detection
    - Implement NIR sensor readings with IRLED control for paper moisture measurement
    - Add calibration system for dry and wet baseline values with linear interpolation
    - Implement paper detection logic using reflected light intensity thresholds
    - Add saturation handling and automatic gain adjustment for sensor readings
    - Implement retry mechanism (max 3 attempts) with configurable measurement intervals
    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
2025-12-08 Refactor and enhance frontend and backend modules
    - Updated SerialPubSub.h to reduce maximum subscriptions, topic length, and message length for optimized performance.
    - Enhanced app.js to load new modules for IR LED control and sensor LED control.
    - Improved pubsub_client.js to notify global message handlers for debugging purposes.
    - Streamlined fan_control.html for cleaner code and improved functionality.
    - Added new irled_control.html module for controlling IR LED with status updates.
    - Updated moisture_sensor.html to include LED status indicator and handle LED status updates.
    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
2025-12-09 Refactor: 去掉as7341，他被烧坏了
2025-12-09 feat(frontend,backend): 增加步进电机位置跟踪和控制功能
2025-12-09 refactor: 移除不再使用的IR LED控制和传感器LED控制模块
2025-12-09 feat(frontend,backend): 添加移动到指定位置功能及相关表单验证
2025-12-09 feat: Add DHT Sensor and Heater Control modules with real-time data display and control features
    - Implemented DHT Sensor module for temperature and humidity readings with calibration options and data visualization using Chart.js.
    - Created Heater Control module for managing heater power settings with slider and quick control buttons.
    - Enhanced index.html to include new modules and improved layout.
    - Added error handling and connection status monitoring for both modules.
    [PaperProtector.ino, SerialPubSub.cpp, serial_handler.py]
2025-12-09 feat: 增加加热器和DHT传感器的调试信息，优化订阅数量
2025-12-09 feat: 优化DHT22传感器读取间隔，增加EMA滤波处理；更新前端显示格式化函数
2025-12-09 fix: 使用_mmPerRevolution计算位置，确保与moveTo一致
2025-12-09 refactor: 清理DHT22Sensor和SerialPubSub类中的注释，优化代码可读性
2025-12-10 feat: 添加纸张保护器主界面，包含调试仪表板和位置模拟功能
2025-12-10 feat: 删除桥接服务器的启动脚本，添加系统状态指示器和样式
2025-12-10 feat: 添加Paper Protector v13.f3d文件
    [Paper Protector v13.f3d]
2025-12-10 feat: 添加湿度柱状图和电机校准按钮，优化用户界面交互
2026-01-09 feat: Implement Paper Protector Simulator and enhance UI styles
    - Added a new simulator for the Paper Protector system to simulate sensor data and motor behavior.
    - Updated CSS styles for the paper interface, including new visualization wrappers, paper sections, and humidity chart styles.
    - Introduced connection indicator styles for better user feedback.
    - Enhanced wet spot representation with background blur effects for improved visual clarity.
    - Improved humidity bar representation and added animations for dynamic updates.
    - Created a README file to provide an overview and documentation for the project.
2026-01-12 feat: 更新配置和扫描逻辑，添加调试信息和用户提示
2026-01-12 feat: 更新README.md，添加系统功能描述、硬件清单和使用说明
